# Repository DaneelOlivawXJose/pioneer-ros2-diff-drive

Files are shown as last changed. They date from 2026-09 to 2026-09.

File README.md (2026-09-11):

<div align="center">

# 🤖 Pioneer-X | Autonomous Differential Drive Robot

### A full-stack robotics project — from Electronics to real-time control dashboards

**Mechanical design · Electronics · Embedded firmware · ROS 2 · Control Algorithms · Custom SCADA (React)**







<!-- 🖼️ PLACEHOLDER: Add more badges if relevant — e.g. Docker, KiCad, Fusion360, micro-ROS, Node version -->

</div>

---

## 📌 About this project

This is a **fully built, working, from-scratch differential-drive mobile robot**, inspired by the classic Pioneer research platforms — but extended into a complete robotics stack that could be upgraded any time.

This repository is **not a tutorial**. It is a **portfolio**: the complete set of design files, source code, firmware, and control software behind a robot that physically exists, drives, localizes itself, and can be commanded and monitored in real time through a custom web-based SCADA I built in React.

> ⚠️ *This is proof-of-work documentation. Build instructions, BOM sourcing tips, and step-by-step guides are intentionally out of scope — the goal is to showcase the integrated system as it currently stands.*

### 🚧 Status: Active Development

This project is **not a closed, finished product** — it's designed and built as an **open testbed platform**. The mechanical structure, electronics, firmware, and ROS 2 architecture were all built with extensibility as a first-class goal:

- 🧩 **New control/path-tracking algorithms** can be dropped in as independent ROS 2 nodes and selected live from the SCADA, without touching the rest of the stack.
- 🔌 **New hardware accessories** (sensors, actuators, additional boards) can be integrated thanks to the modular electronics layout and the firmware/ROS 2 separation of concerns.
- 🧪 The whole point of the SCADA is to make this platform easy to **test, compare, and iterate on** — swap an algorithm, watch the telemetry, tune it, repeat.

In short: this repo is a living platform for experimenting with mobile robot control and hardware, not a one-off build. Expect ongoing commits, new algorithms, and new accessories over time — see the [Roadmap](#-roadmap).

<!-- ✍️ DEVELOP MORE: 1-2 paragraphs here about WHY you built this — personal motivation, what gap you wanted to fill, what you wanted to learn/prove (control theory? full-stack robotics? SCADA/HMI design? building an extensible research platform?). This is the part recruiters/visitors read first. -->

---

## 🎥 Demonstrations

<!-- 🖼️ PLACEHOLDER: This section sells the project. Embed real GIFs/videos. GitHub renders GIFs inline; for longer videos, link to YouTube with a thumbnail. -->

| Autonomous navigation | Real-time SCADA monitoring | Manual teleoperation |
|---|---|---|
| nav | scada | teleop |

<!-- ✍️ DEVELOP MORE: Add a "Full demo video" section here with a YouTube/Drive link, ideally 2-4 minutes showing: boot-up, teleop, autonomous path-following with each algorithm, and the SCADA reacting live. -->

---

## 🧭 Table of Contents

- [System Overview](#-system-overview)
- [Hardware](#-hardware)
- [Electronics & Wiring](#-electronics--wiring)
- [Firmware (ESP32)](#-firmware-esp32)
- [ROS 2 Software Stack](#-ros-2-software-stack)
- [Control & Path-Tracking Algorithms](#-control--path-tracking-algorithms)
- [SCADA / Web HMI (React)](#-scada--web-hmi-react)
- [Localization](#-localization)
- [Repository Structure](#-repository-structure)
- [Tech Stack Summary](#-tech-stack-summary)
- [Results & Performance](#-results--performance)
- [Roadmap](#-roadmap)
- [License](#-license)
- [Author](#-author)

---

## 🏗️ System Overview

<!-- 🖼️ PLACEHOLDER: High-level architecture diagram — boxes for ESP32 <-> micro-ROS/serial <-> ROS2 (Nav stack, controllers, EKF) <-> rosbridge/WebSocket <-> React SCADA. Draw it in draw.io/excalidraw and export as PNG/SVG into docs/media/ -->

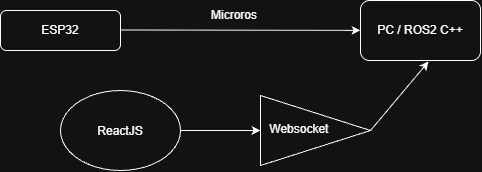
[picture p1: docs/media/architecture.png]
Architecture Diagram


The robot is organized into three integrated layers:

| Layer | Responsibility | Tech |
|---|---|---|
| **Low-level control** | Motor driving, encoder reading, PID velocity loops, sensor interfacing | ESP32 (C/C++) |
| **High-level autonomy** | Localization, path planning, trajectory tracking, control algorithms | ROS 2 |
| **Supervision (SCADA)** | Real-time visualization, teleoperation, algorithm selection, telemetry | React + WebSocket/rosbridge |

<!-- ✍️ DEVELOP MORE: Describe the communication pipeline in detail — e.g. "ESP32 publishes wheel odometry over serial/micro-ROS at X Hz, ROS2 fuses it with IMU via robot_localization EKF, Nav2/custom controller node computes cmd_vel, rosbridge_server exposes topics over WebSocket, React subscribes via roslibjs." -->

---

## ⚙️ Hardware

<!-- 🖼️ PLACEHOLDER: CAD renders — exploded view, chassis, wheel assembly, top view with dimensions -->

<p align="center">
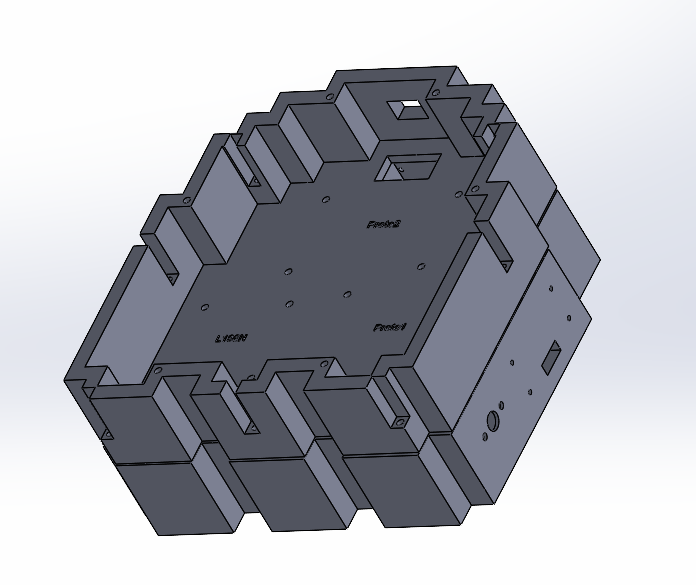
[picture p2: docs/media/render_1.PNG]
  
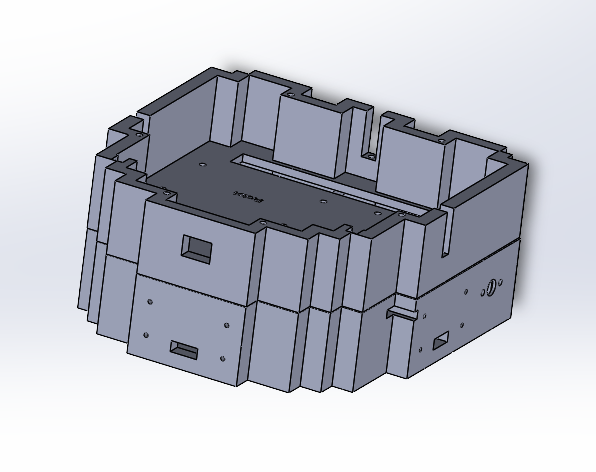
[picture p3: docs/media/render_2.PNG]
  
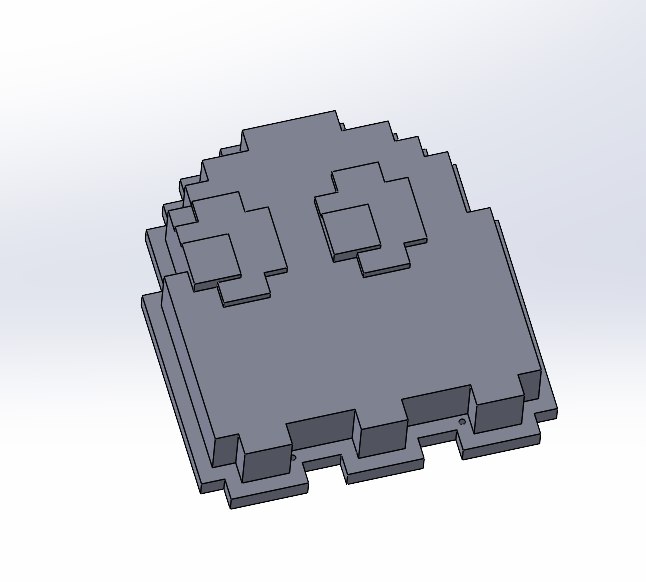
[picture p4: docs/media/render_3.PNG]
  
</p>

- **Chassis:** custom-designed, differential drive, [material/manufacturing — 3D printed]
- **Drive:** 2x DC gear motors + encoders, L298 Driver.
- **CAD files:** provided in [`/hardware/cad`](./hardware/cad) (STEP, native format, and STL for printing)

📄 **Full Bill of Materials:** [`/hardware/BOM.xlsx`](./hardware/BOM.xlsx)

<!-- ✍️ DEVELOP MORE: Table with key specs — dimensions, weight, wheel diameter, wheelbase, max speed, battery/autonomy, payload, sensor list (LiDAR? camera? IMU? ultrasonic?). This is important for anyone evaluating the robot's real capabilities. -->

| Spec | Value |
|---|---|
| Dimensions (L×W×H) | 500x450x100 mm |
| Weight | 600g |
| Max linear speed | 4.0 m/s |
| Battery / autonomy | 3h |

---

## 🔌 Electronics & Wiring

- Pin mapping source of truth: [`/firmware/esp32_code/esp32_code.ino`](./firmware/esp32_code/esp32_code.ino) — every pin below is taken directly from the running firmware, not from a separate (and easily outdated) diagram.
### Core components
 
| Component | Qty | Role | Notes |
|---|---|---|---|
| **ESP32 Dev Board** | 1 | Main controller — runs micro-ROS, PID loops, sensor filtering | Communicates with the ROS 2 side over WiFi via micro-ROS (`set_microros_wifi_transports`) |
| **L298N Dual H-Bridge** | 1 | Drives both DC motors | Controlled via 2 PWM-capable pins per motor (no separate ENA/ENB — direction and speed are combined through both inputs, see table below) |
| **DC Gearmotor + Encoder** | 2 | Traction (differential drive) | Quadrature encoders, read via hardware interrupts on both channels for direction-aware counting |
| **US-016 Analog Ultrasonic Sensor** | 3 | Front obstacle detection | Each sensor has its own dedicated **2nd-order Butterworth low-pass filtering circuit** on the analog output before reaching the ESP32 ADC |
| **18650 Li-ion cells** | 2 | Main power source for motors/logic rail | Feed the charger/boost module below |
| **Type-C Li-ion Charger + DC-DC Boost Module (15 W, 3 A, 9 V out, UPS-style)** | 1 | Battery management + step-up to 9 V | Charges the 2×18650 pack via USB-C while also acting as a boost converter, delivering a stable 9 V rail to the L298N — UPS-style topology means the robot can charge and stay powered at the same time |
| **Phone power bank** | 1 | Dedicated 5 V supply for the ESP32 | Electrically decoupled from the motor power rail — keeps motor-driver switching noise away from the microcontroller's logic supply. Prevents shutting down due to current |
 
<!-- ✍️ DEVELOP MORE: link your exact ESP32 board model, L298N vendor, DC motor/encoder specs (gearbox ratio, encoder PPR), and add real purchase/datasheet links where you have them. -->
 
### Power architecture
 
The robot deliberately runs **two independent power domains**:
 
1. **Motor / actuation rail (9 V):** 2×18650 cells → Type-C charger/boost module → 9 V → L298N → motors. The boost module's UPS behavior allows charging without powering the robot down.
2. **Logic rail (5 V):** a standalone phone power bank feeds the ESP32 directly over USB.
This separation avoids voltage sag and PWM switching noise from the motors affecting the ESP32's ADC readings — which matters here, since the ultrasonic sensors are read as raw analog voltages and are sensitive to supply noise.
Also sometimes when starting the motors, the current was so high that restarted all the system, this power bank prevents this issue.
 
### Motor driver (L298N) pin mapping
 
| Signal | ESP32 Pin | Notes |
|---|---|---|
| Left motor – IN1 | `GPIO 32` | PWM output (`ledcAttach`, 25 kHz, 10-bit) |
| Left motor – IN2 | `GPIO 33` | PWM output |
| Right motor – IN1 | `GPIO 27` | PWM output |
| Right motor – IN2 | `GPIO 14` | PWM output |
 
Each motor is driven by **two PWM channels instead of a PWM+direction pair**: forward/reverse and speed are both encoded by driving one of the two `INx` pins with a PWM duty cycle while the other stays at 0 (see `setMotorL` / `setMotorR` in the firmware). This removes the need for separate `ENA`/`ENB` enable lines.
 
### Encoders (quadrature, interrupt-driven)
 
| Signal | ESP32 Pin | Notes |
|---|---|---|
| Left encoder – Channel A | `GPIO 25` | `INPUT_PULLUP`, `CHANGE` interrupt |
| Left encoder – Channel B | `GPIO 26` | `INPUT_PULLUP`, `CHANGE` interrupt |
| Right encoder – Channel A | `GPIO 12` | `INPUT_PULLUP`, `CHANGE` interrupt |
| Right encoder – Channel B | `GPIO 13` | `INPUT_PULLUP`, `CHANGE` interrupt |
 
Both channels of each encoder trigger their own ISR, comparing A/B state to determine direction — giving full quadrature resolution (4x counting) rather than relying on a single edge.
 
### Ultrasonic sensors (US-016, analog)
 
| Signal | ESP32 Pin | ADC | Notes |
|---|---|---|---|
| Sensor 1 (analog out) | `GPIO 36` | ADC1_CH0 | Voltage divider + 2nd-order Butterworth filter upstream |
| Sensor 2 (analog out) | `GPIO 39` | ADC1_CH3 | Voltage divider + 2nd-order Butterworth filter upstream |
| Sensor 3 (analog out) | `GPIO 34` | ADC1_CH6 | 2nd-order Butterworth filter upstream (read directly in mV, no divider) |
 
All three run on ADC1 (safe to use alongside WiFi, unlike ADC2). Each sensor's raw output passes through a dedicated **2nd-order Butterworth low-pass filter** before reaching the ESP32, reducing high-frequency noise at the hardware level; the firmware then applies a further **median filter (7 samples) + exponential smoothing (α = 0.3)** in software, read continuously from a dedicated FreeRTOS task (`tareaLecturaUS016`) so sensor sampling never blocks the ROS 2 executor or the PID control loop.
 
### Status LED
 
| Signal | ESP32 Pin | Notes |
|---|---|---|
| Onboard status LED | `GPIO 2` | Blinks/toggles on obstacle detection and on odometry reset, doubles as a fatal-error indicator (`error_loop`) |
 
<!-- 🖼️ PLACEHOLDER: A labeled photo of the real wiring inside the chassis, matching the tables above, is worth more here than any diagram. -->

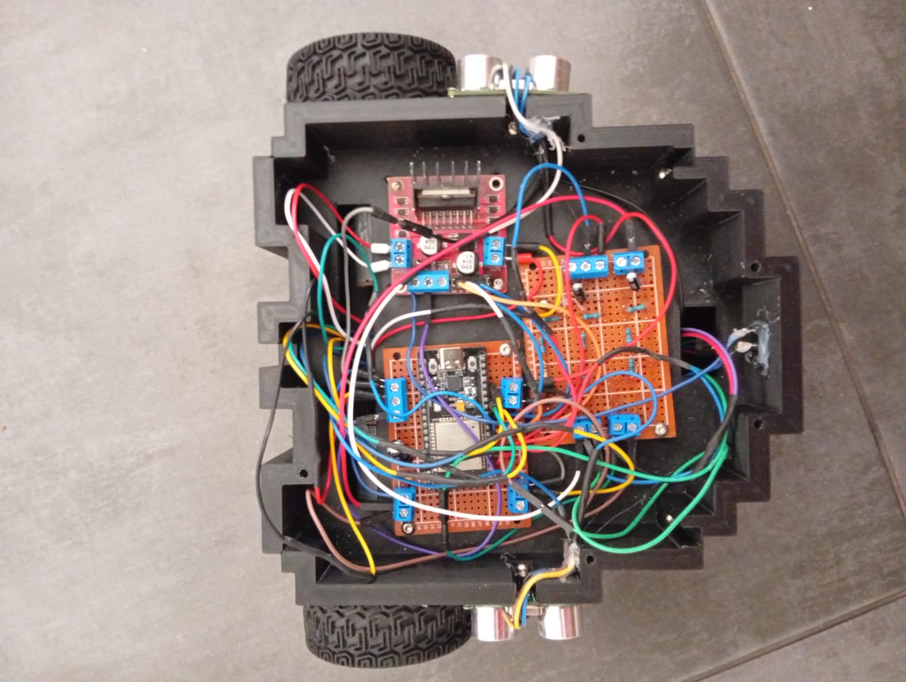
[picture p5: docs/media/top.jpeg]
Top-down view

 
---

## 🐢 ROS 2 Software Stack

Location: [`/ros2_ws/src`](./ros2_ws/src)

<!-- 🖼️ PLACEHOLDER: rqt_graph screenshot showing your actual node/topic graph -->

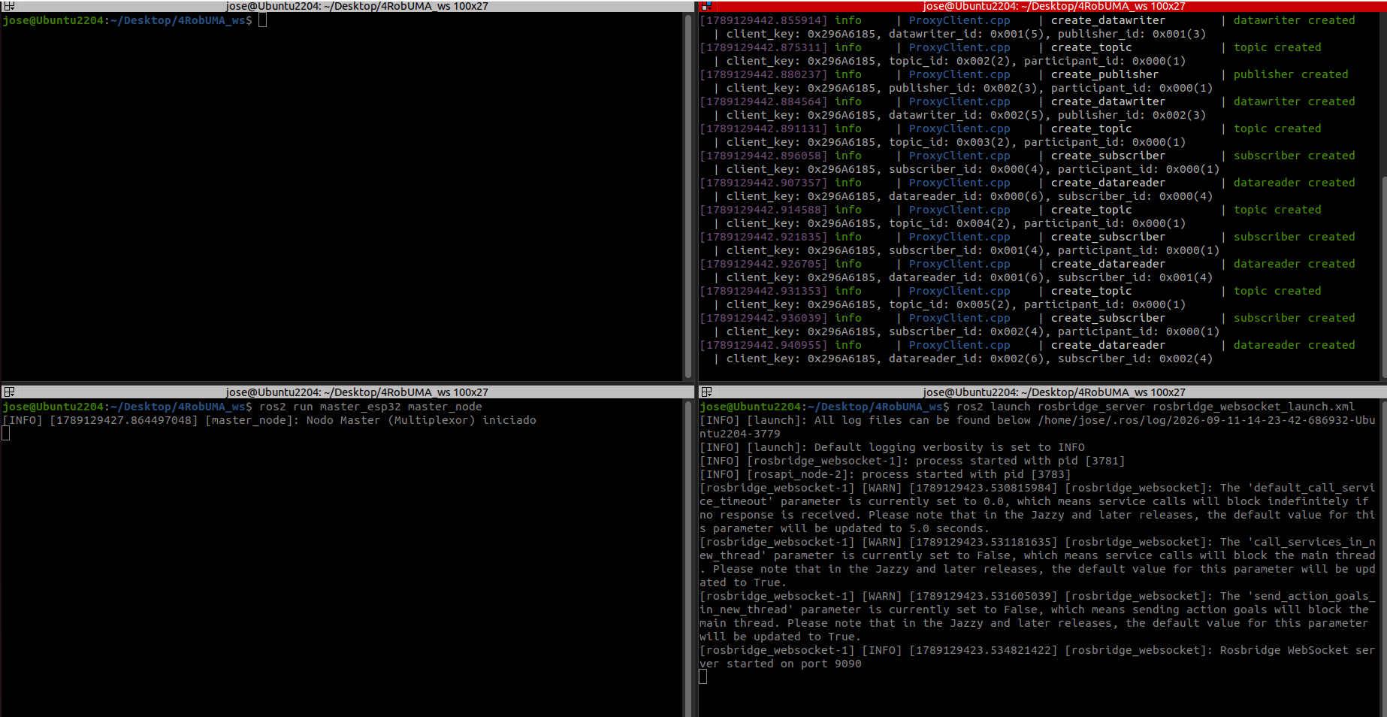
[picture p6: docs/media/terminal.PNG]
Ubuntu Terminal


Custom ROS 2 packages built for this robot. The architecture keeps control algorithms and hardware interfaces decoupled into their own packages/nodes, so new ones can be added without modifying the core stack.

### 🧠 Master / Orchestrator architecture
 
Rather than launching every control node at once and switching behavior through internal flags, this stack uses a **master (orchestrator) node** that supervises which algorithm is actually running:
 
1. The **master node** stays up permanently, subscribed to a command topic (e.g. `/control/select_algorithm`).
2. When a command arrives on that topic — coming from the SCADA, a CLI call, or any other client — the master **launches the corresponding control node as its own process** (e.g. `ros2 run pioneer_control mpc_node`), rather than that node being active from boot.
3. The incoming message is **forwarded to the newly launched node** (as a parameter, an initial topic message, or a service call, depending on the node), so it starts already configured with the requested behavior.
4. If a different algorithm is requested while one is already running, the master **stops/kills the current control node's process first**, then spawns the new one — guaranteeing only one control node is ever commanding the robot at a time.
This keeps every control algorithm fully decoupled: each one lives in its own node/process, with no shared state, and the master is the single source of truth for *which* algorithm currently owns `cmd_vel`. Adding a new algorithm means writing a new node and registering it with the master — no changes to the rest of the stack.
 
### ▶️ How to Run
 
Typical startup sequence, in order:
 
1. **Start the micro-ROS agent** (bridges the ESP32's WiFi micro-ROS client to the ROS 2 graph):
```bash
   ros2 run micro_ros_agent micro_ros_agent udp4 --port 8888
```
 
2. **Power on the robot / reset the ESP32** so it connects to the agent above (watch the serial monitor or the agent log for a successful handshake).
3. **Launch the rosbridge server**
```bash
   ros2 launch rosbridge_server rosbridge_websocket_launch.xml
```
 
4. **Launch the master/orchestrator node**, which will stay running and wait for algorithm-selection commands:
```bash
   ros2 run master_esp32 master_node
```
 
5. **Start the SCADA dashboard**:
```bash
   npm run dev
```

## 🎯 Control & Path-Tracking Algorithms

One of the standout features of this project: the robot supports **multiple, hot-swappable trajectory-tracking algorithms**, selectable live from the SCADA.

| Algorithm | Description | Status |
|---|---|---|
| **Proportional** | Classic proportional controller | ✅ Implemented |
| **Follow the Carrot** | Classic pursuit of a moving lookahead point on the path | ✅ Implemented |
| **MPC (Model Predictive Control)** | Optimization-based control over a prediction horizon | ✅ Implemented |
| **Implicit Path Following** | Based on references like 1 wall / 2 wall / Moving objective | ✅ Implemented |

<!-- ✍️ DEVELOP MORE: This is your strongest technical differentiator — expand heavily here.
For EACH algorithm, add:
- Short explanation of the math/approach used
- Key tunable parameters (lookahead distance, horizon length, weights, constraints)
- A GIF/plot comparing behavior (e.g. tracking error over time) between algorithms on the same path
- Why you chose to implement each one / what you learned
Consider linking to a `/docs/control_theory.md` or similar for the deep technical writeup, and keeping this section as a summary. -->
Every algorithm is tunnable from scada:
| Pure Pursuit | MPC |
|---|---|
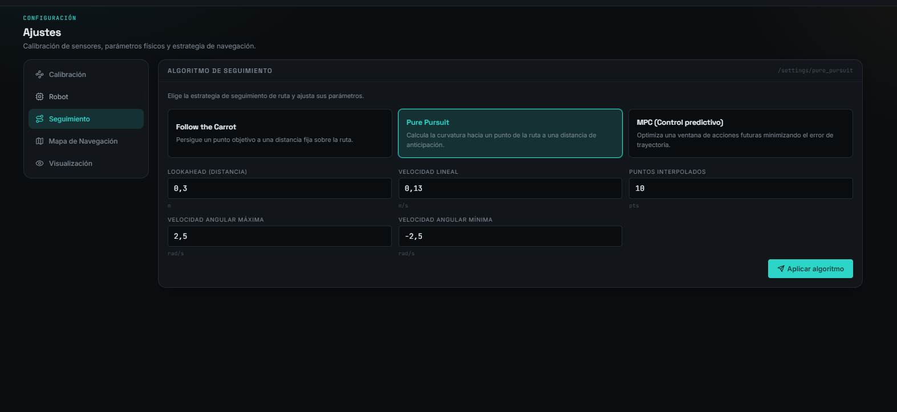
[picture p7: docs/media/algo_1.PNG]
Pure Pursuit
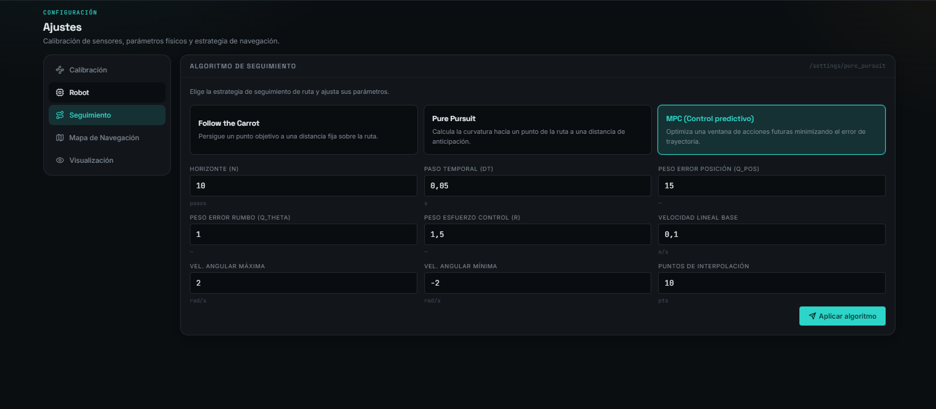
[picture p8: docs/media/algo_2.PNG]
MPC
|  |  |

---

## 🖥️ SCADA / Web HMI (React)

Location: [`/scada`](./scada)

<!-- 🖼️ PLACEHOLDER: Screenshot or GIF of the dashboard — ideally a few, showing: live map/localization, telemetry panel, algorithm selector, manual command panel -->

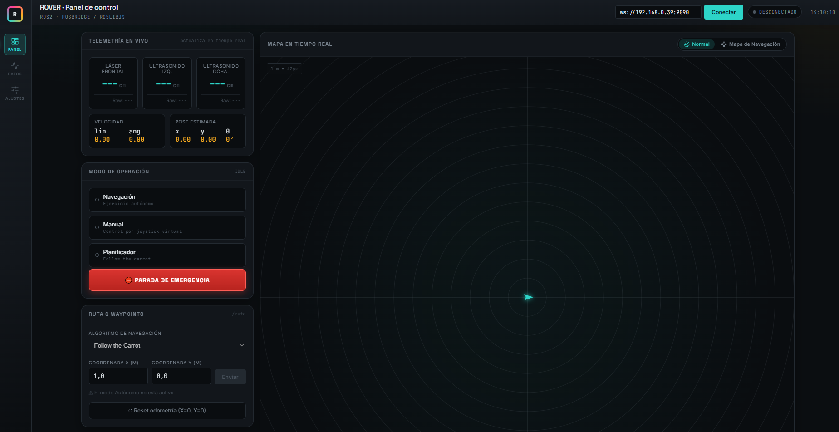
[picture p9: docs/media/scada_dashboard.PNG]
SCADA Dashboard


A custom-built, real-time supervisory dashboard, developed entirely in React, that connects directly to the ROS 2 stack:

- 📍 **Real-time localization view** — live robot pose over the map/path
- 🎮 **Manual command interface** — teleoperation, direct velocity commands
- 🤖 **Robot parameters tunner** — width, wheel radius, ...
- 🔀 **Algorithm selector** — switch between MPC / Follow the Carrot / others on the fly
- 📊 **Live telemetry** — velocities, battery, control errors, system status
- 📡 **Sensor Calibration** — lineal, cuadratic, least square adjustment
- 🛑 **Safety controls** — *(e-stop, connection status, etc)*

**Stack:** React, [state management — Redux/Zustand/Context], [charting — Recharts/D3/Plotly], [ROS bridge — roslibjs + rosbridge_suite / custom WebSocket server]

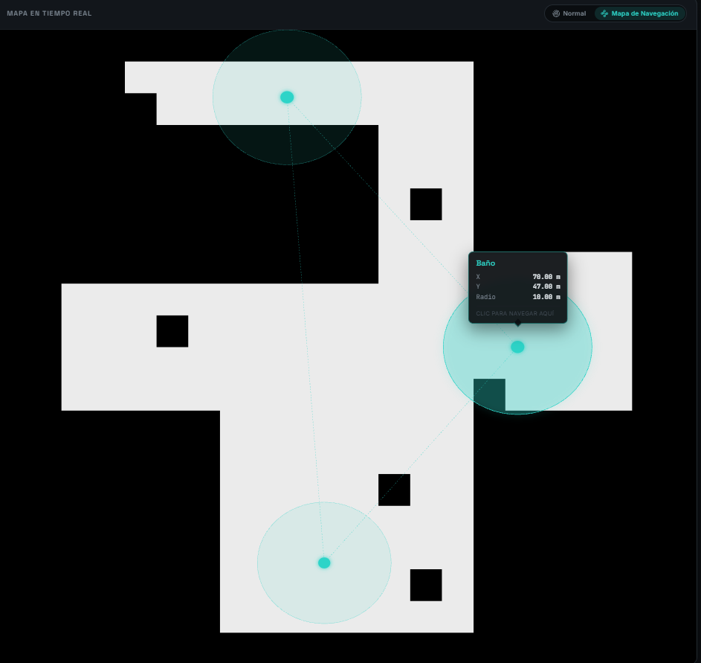
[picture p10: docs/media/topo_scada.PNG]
SCADA Topologic Planning


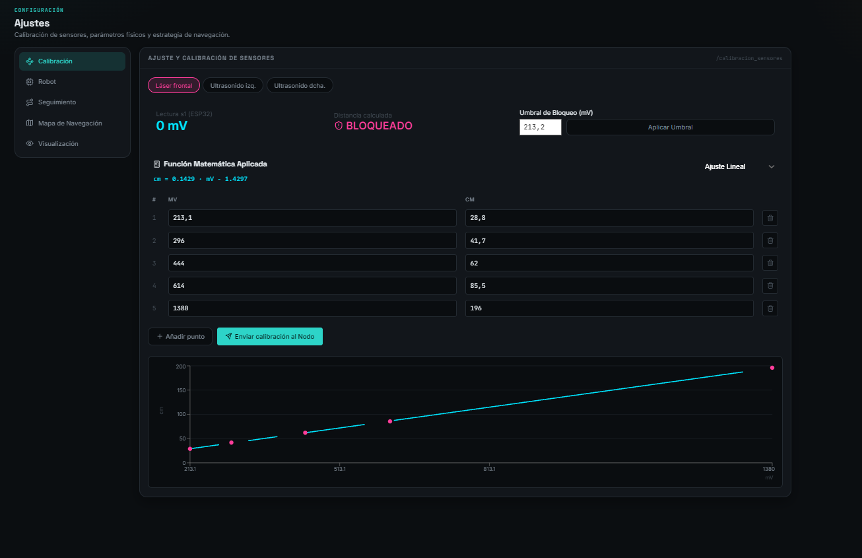
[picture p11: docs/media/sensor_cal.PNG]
SCADA Sensor Calibration


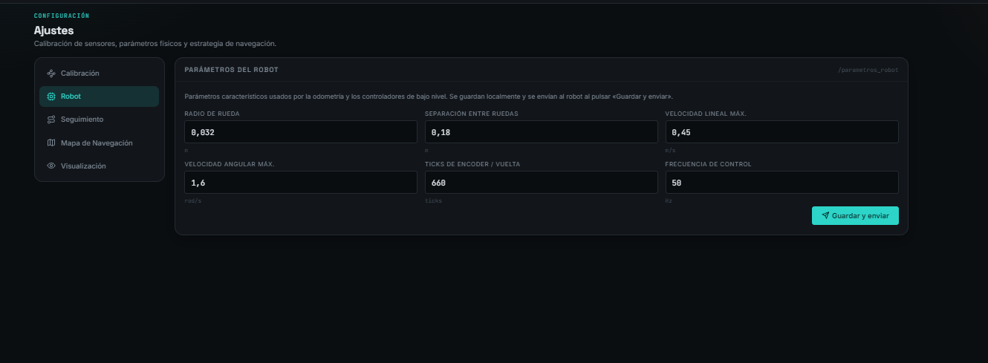
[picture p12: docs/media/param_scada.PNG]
SCADA Robot Parameters


## 🧰 Tech Stack Summary

<div align="center">








</div>

---

## 🗺️ Roadmap

<!-- ✍️ DEVELOP MORE: List what's next — shows the project is alive and you have vision beyond "finished." e.g.: -->

- [ ] SLAM-based mapping support
- [ ] Multi-robot fleet view in SCADA
- [ ] Obstacle avoidance layer
- [ ] Dockerized ROS 2 + SCADA deployment
- [ ] Simulation environment (Gazebo/Ignition digital twin)

---

## 📄 License

This project is licensed under the [MIT License](./LICENSE) — feel free to reference or learn from it; attribution appreciated.

<!-- ✍️ Confirm this matches your actual chosen license (MIT / Apache-2.0 / GPL, etc.) and add the LICENSE file to the repo root. -->

---

## 👤 Author

**Jose Segura Montes**
Robotics / Mechatronics engineer

<!-- ✍️ DEVELOP MORE: Add links — LinkedIn, personal site, email, other projects -->




<div align="center">

*4 8 15 16 23 42*

</div>

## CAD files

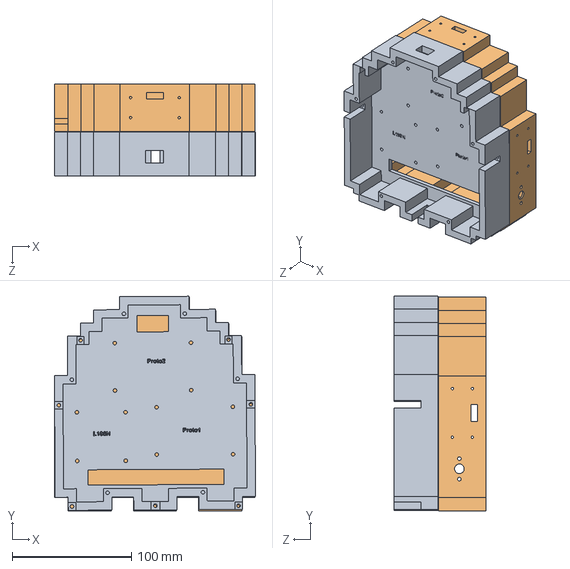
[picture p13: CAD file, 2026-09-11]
hardware/cad/EnsamblajeRobot.SLDASM
168.7 x 180.0 x 77.6 mm
MainBase
ParteElectronica

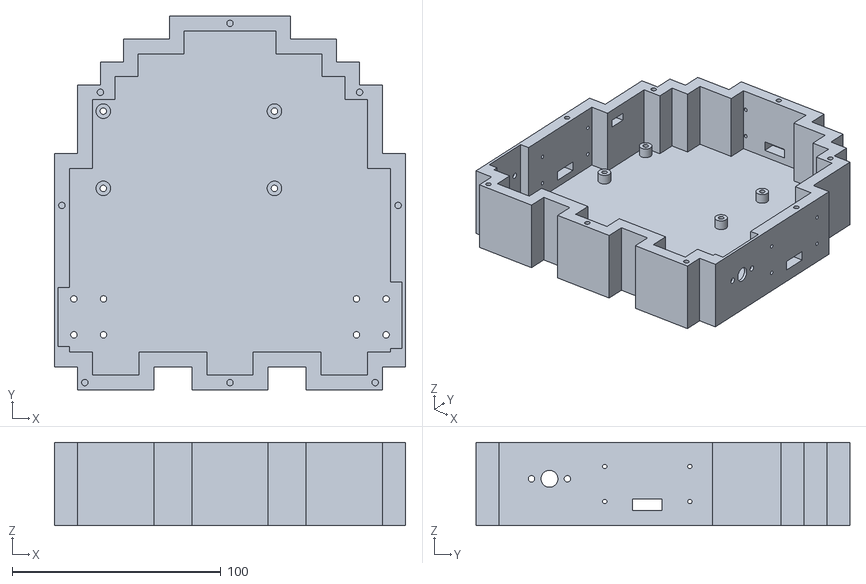
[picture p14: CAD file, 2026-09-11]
hardware/cad/Imprimir/MainBase.STL
168.2 x 179.2 x 40.0

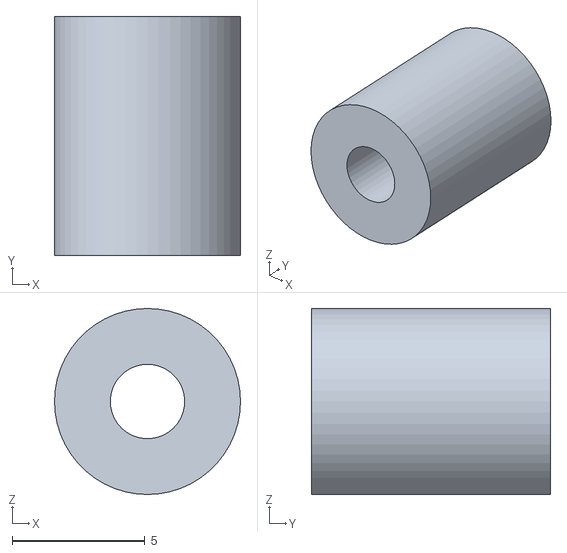
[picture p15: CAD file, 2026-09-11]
hardware/cad/Imprimir/SoportesAtornillas.STL
7.00 x 9.00 x 7.00

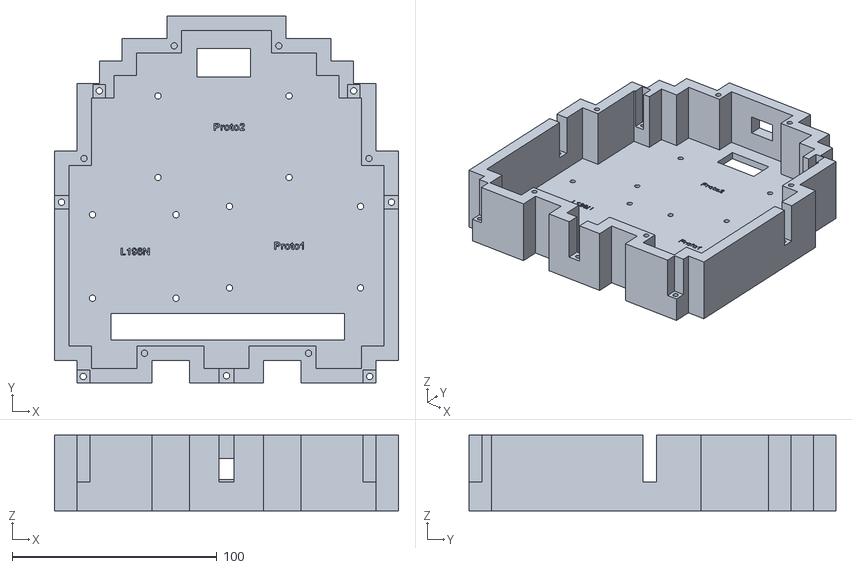
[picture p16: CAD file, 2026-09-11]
hardware/cad/Imprimir/ParteElectronica.STL
168.2 x 179.2 x 37.0

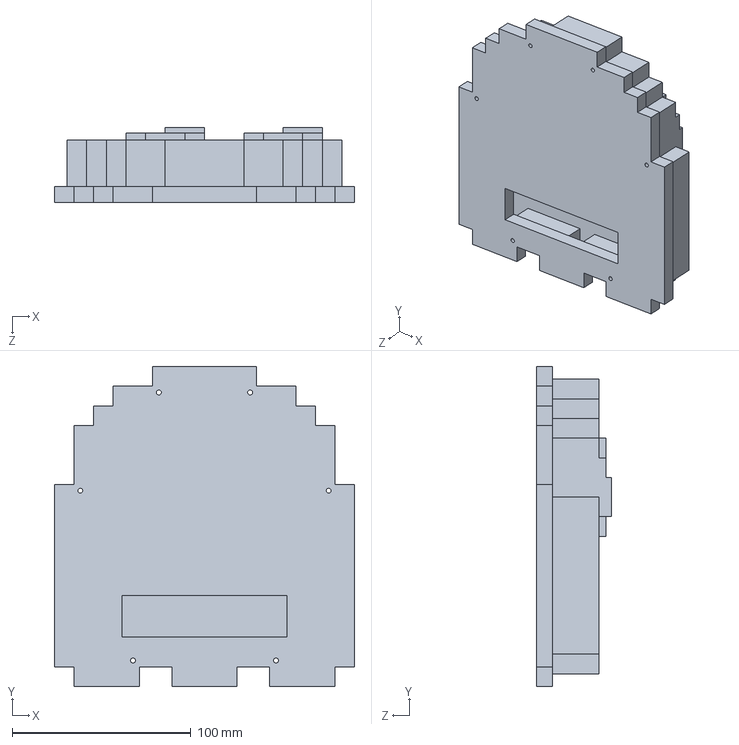
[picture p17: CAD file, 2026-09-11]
hardware/cad/Tapa.SLDPRT
168.2 x 179.2 x 42.0 mm

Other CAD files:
hardware/cad/MainBase.SLDPRT
hardware/cad/SoportesAtornillas.SLDPRT
hardware/cad/Imprimir/Tapa.STL
hardware/cad/ParteElectronica.SLDPRT

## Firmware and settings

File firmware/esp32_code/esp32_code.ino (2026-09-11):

#include <Arduino.h>
#include <micro_ros_arduino.h>
#include <stdio.h>
#include <rcl/rcl.h>
#include <rcl/error_handling.h>
#include <rclc/rclc.h>
#include <rclc/executor.h>
#include <std_msgs/msg/string.h>
#include <geometry_msgs/msg/twist.h>
#include <geometry_msgs/msg/point.h>
#include <std_msgs/msg/int32_multi_array.h>
#include <std_msgs/msg/int32.h>
#include <std_msgs/msg/float32_multi_array.h>
#include <WiFi.h>

#if !defined(ESP32)
#error This example is only available for ESP32
#endif

// ==========================================
//   CONFIGURACIÓN
// ==========================================

rcl_node_t node;
rclc_support_t support;
rcl_allocator_t allocator;
rclc_executor_t executor;

// Publicadores
rcl_publisher_t publisher; // Odometría (ticks)
rcl_publisher_t publisher_laser; // Sensor Distancia (MultiArray)
rcl_publisher_t pub_pos_estimada;
std_msgs__msg__Int32MultiArray encoder_msg;
std_msgs__msg__Float32MultiArray laser_msg; // Mensaje de 3 posiciones
geometry_msgs__msg__Point pos_msg;

// Suscriptor
rcl_subscription_t subscriber;
geometry_msgs__msg__Twist msg_sub;

rcl_subscription_t subscriber_settings;
std_msgs__msg__Float32MultiArray msg_sub_settings;

rcl_subscription_t subscriber_reset;
std_msgs__msg__Int32 msg_reset;

// PINES
#define LED_PIN 2

// --- VARIABLES DE ESTADO ---
volatile bool sistema_seguro = false;
volatile bool obstaculo_delante = false;

const int frecuencia = 25000;

// --- MOTORES ---
const int IN1_L = 32; const int IN2_L = 33;
const int PIN_A_L = 25; const int PIN_B_L = 26; 
const int IN1_R = 27; const int IN2_R = 14;
const int PIN_A_R = 12; const int PIN_B_R = 13; 

// --- CINEMÁTICA Y PID ---
const double RADIO_RUEDA = 0.0347;
const double ANCHO_ROBOT = 0.1941;
const float DELTA_T_S = 0.01; // 10ms
const float CUENTAS_POR_REV_TOTAL = 1564.65;
const float FACTOR_CUENTAS_A_RADS = (2.0 * 3.14159265) / CUENTAS_POR_REV_TOTAL;

double pos_x_global = 0.0;
double pos_y_global = 0.0;
double theta_actual = 0.0;
long sl_prev = 0;
long sr_prev = 0;

// PID CONSTANTES
const double Kp_L = 40.289; const double Ki_L = 1120.3135; const double Kd_L = 0.0;
const double Kp_R = 19.6078; const double Ki_R = 586.746; const double Kd_R = 0.0;

// Variables PID
volatile double target_L = 0.0;
volatile double target_R = 0.0;

volatile long contador_L = 0;
long contador_L_ant = 0;
double error_acumulado_L = 0.0;
double error_anterior_L = 0.0;

volatile long contador_R = 0;
long contador_R_ant = 0;
double error_acumulado_R = 0.0;
double error_anterior_R = 0.0;

// Hardware Timers y Mux
hw_timer_t *timer = NULL;
portMUX_TYPE timerMux = portMUX_INITIALIZER_UNLOCKED;
portMUX_TYPE paramMux = portMUX_INITIALIZER_UNLOCKED;

#define RCCHECK(fn) { \
  rcl_ret_t temp_rc = fn; \
  if ((temp_rc != RCL_RET_OK)) { \
    Serial.print("Fallo en inicialización de ROS. Código de error: "); \
    Serial.println((int)temp_rc); \
    Serial.println("Reiniciando ESP32 en 3 segundos..."); \
    delay(3000); \
    ESP.restart(); \
  } \
}
#define RCSOFTCHECK(fn) { rcl_ret_t temp_rc = fn; if((temp_rc != RCL_RET_OK)){ Serial.print("MicroROS Error Code: "); Serial.println((int)temp_rc); }}

// ==========================================
//   CONFIGURACIÓN DE SENSORES US-016
// ==========================================
const int NUM_MUESTRAS = 7;
const float MULTIPLICADOR_RC = 1.5; // Divisor de tensión (3/2)
const float alfa = 0.3;

struct US016Sensor {
  uint8_t pin;
  float lecturas[NUM_MUESTRAS];
  float voltaje_mV;
  float voltaje_mV_anterior_suavizado;
  float voltaje_mV_minimo;
};

// Instanciamos los 3 sensores
US016Sensor sensores[3] = {
  {36, {0}, 0.0, 0.0, 100.0},
  {39, {0}, 0.0, 0.0, 100.0},
  {34, {0}, 0.0, 0.0, 100.0}
};

float obtenerMediana(float array[], int size)
{
  float tempArray[size];
  memcpy(tempArray, array, size * sizeof(float));
  
  for(int i = 0; i < (size - 1); i++) {
    for(int j = 0; j < (size - (i + 1)); j++) {
      if(tempArray[j] > tempArray[j+1]) {
        float t = tempArray[j];
        tempArray[j] = tempArray[j+1];
        tempArray[j+1] = t;
      }
    }
  }
  return tempArray[size / 2];
}

void inicializarSensor(US016Sensor &sensor)
{
  for (int i = 0; i < NUM_MUESTRAS; i++) {
    sensor.lecturas[i] = analogReadMilliVolts(sensor.pin) * MULTIPLICADOR_RC;
    delay(20);
  }
  float medianaInicial = obtenerMediana(sensor.lecturas, NUM_MUESTRAS);
  sensor.voltaje_mV = medianaInicial;
  sensor.voltaje_mV_anterior_suavizado = medianaInicial;
}



// Tarea en segundo plano para leer y filtrar
void tareaLecturaUS016(void *pvParameters)
{
  for(;;)
  {
    for (int s = 0; s < 3; s++)
    {
      for (int i = 0; i < NUM_MUESTRAS - 1; i++)
      {
        sensores[s].lecturas[i] = sensores[s].lecturas[i + 1];
      }

      float nuevaLectura_mV = 0.0;
      if (sensores[s].pin != 34)
      {
        nuevaLectura_mV = analogReadMilliVolts(sensores[s].pin) * MULTIPLICADOR_RC;
      } else {
        nuevaLectura_mV = analogReadMilliVolts(sensores[s].pin);
      }
      
      sensores[s].lecturas[NUM_MUESTRAS - 1] = nuevaLectura_mV;

      float mediana = obtenerMediana(sensores[s].lecturas, NUM_MUESTRAS);

      sensores[s].voltaje_mV = alfa * mediana + (1 - alfa) * sensores[s].voltaje_mV_anterior_suavizado;
      sensores[s].voltaje_mV_anterior_suavizado = sensores[s].voltaje_mV;
    }
    vTaskDelay(pdMS_TO_TICKS(50));
  }
}

// ==========================================
//   FUNCIONES BÁSICAS Y RUTINAS
// ==========================================
void pararMotores()
{
  ledcWrite(IN1_L, 0); ledcWrite(IN2_L, 0);
  ledcWrite(IN1_R, 0); ledcWrite(IN2_R, 0);
}

void error_loop() {
  Serial.println("!!! ERROR FATAL !!!");
  pararMotores();
  while (1) {
    digitalWrite(LED_PIN, !digitalRead(LED_PIN)); delay(200);
  }
}

void IRAM_ATTR isr_L_A() { if(digitalRead(PIN_A_L)==digitalRead(PIN_B_L)) contador_L--; else contador_L++; }
void IRAM_ATTR isr_L_B() { if(digitalRead(PIN_A_L)!=digitalRead(PIN_B_L)) contador_L--; else contador_L++; }
void IRAM_ATTR isr_R_A() { if(digitalRead(PIN_A_R)==digitalRead(PIN_B_R)) contador_R++; else contador_R--; } 
void IRAM_ATTR isr_R_B() { if(digitalRead(PIN_A_R)!=digitalRead(PIN_B_R)) contador_R++; else contador_R--; }

void setMotorL(int pwm) {
  if (pwm > 1023) pwm = 1023; if (pwm < -1023) pwm = -1023;
  if (pwm >= 0) { ledcWrite(IN1_L, pwm); ledcWrite(IN2_L, 0); }
  else { ledcWrite(IN1_L, 0); ledcWrite(IN2_L, -pwm); }
}

void setMotorR(int pwm) {
  if (pwm > 1023) pwm = 1023; if (pwm < -1023) pwm = -1023;
  if (pwm >= 0) { ledcWrite(IN1_R, pwm); ledcWrite(IN2_R, 0); }
  else { ledcWrite(IN1_R, 0); ledcWrite(IN2_R, -pwm); }
}

double calcularPID(double ref, double medicion, double &err_acum, double &err_prev, double Kp, double Ki, double Kd) {
  double error = ref - medicion;
  err_acum += error * DELTA_T_S;
  
  double max_I = 1023.0; 
  if (Ki > 0) max_I = 1023.0 / Ki;
  if (err_acum > max_I) err_acum = max_I;
  if (err_acum < -max_I) err_acum = -max_I;

  err_prev = error;
  return (Kp * error) + (Ki * err_acum);
}

void IRAM_ATTR onTimerPID() {
  bool intentando_avanzar = (target_L > 0 && target_R > 0);

  if (!sistema_seguro || (obstaculo_delante && intentando_avanzar)) {
    pararMotores();
    error_acumulado_L=0; error_anterior_L=0;
    error_acumulado_R=0; error_anterior_R=0;
    return;
  }

  double ref_L, ref_R;
  portENTER_CRITICAL_ISR(&paramMux);
  ref_L = target_L; ref_R = target_R;
  portEXIT_CRITICAL_ISR(&paramMux);

  long pos_L, pos_R;
  portENTER_CRITICAL_ISR(&timerMux);
  pos_L = contador_L; pos_R = contador_R;
  portEXIT_CRITICAL_ISR(&timerMux);

  double vel_L = ((double)(pos_L - contador_L_ant) / DELTA_T_S) * FACTOR_CUENTAS_A_RADS;
  double vel_R = ((double)(pos_R - contador_R_ant) / DELTA_T_S) * FACTOR_CUENTAS_A_RADS;
  
  contador_L_ant = pos_L; contador_R_ant = pos_R;

  double out_L = calcularPID(ref_L, vel_L, error_acumulado_L, error_anterior_L, Kp_L, Ki_L, Kd_L);
  double out_R = calcularPID(ref_R, vel_R, error_acumulado_R, error_anterior_R, Kp_R, Ki_R, Kd_R);

  setMotorL((int)out_L); setMotorR((int)out_R);
}

void calcular_posicion() {
  long sl_curr = contador_L;
  long sr_curr = contador_R;

  long delta_l_ticks = sl_curr - sl_prev;
  long delta_r_ticks = sr_curr - sr_prev;
  sl_prev = sl_curr;
  sr_prev = sr_curr;

  double sl = 2.0 * PI * RADIO_RUEDA * ((double)delta_l_ticks / CUENTAS_POR_REV_TOTAL);
  double sr = 2.0 * PI * RADIO_RUEDA * ((double)delta_r_ticks / CUENTAS_POR_REV_TOTAL);

  double dx_l = 0, dy_l = 0, dt = 0;

  if (abs(sr - sl) < 1e-6) {
    dx_l = (sr + sl) / 2.0;
  } else {
    double l = ANCHO_ROBOT;
    double common = ((sr + sl) / (sr - sl)) * (l / 2.0);
    double arg = (sr - sl) / l;
    dx_l = common * sin(arg);
    dy_l = common * (1.0 - cos(arg));
    dt = arg;
  }

  double dx_g = dx_l * cos(theta_actual) - dy_l * sin(theta_actual);
  double dy_g = dx_l * sin(theta_actual) + dy_l * cos(theta_actual);

  pos_x_global += dx_g;
  pos_y_global += dy_g;
  theta_actual += dt;

  while(theta_actual > PI) theta_actual -= 2*PI;
  while(theta_actual < -PI) theta_actual += 2*PI;
}

void reset_callback(const void * msgin) {
  const std_msgs__msg__Int32 * msg = (const std_msgs__msg__Int32 *)msgin;
  if (msg->data == 1) {
    portENTER_CRITICAL(&paramMux);
    pos_x_global = 0.0;
    pos_y_global = 0.0;
    theta_actual = 0.0;
    error_acumulado_L = 0; error_anterior_L = 0;
    error_acumulado_R = 0; error_anterior_R = 0;
    target_L = 0; target_R = 0;
    portEXIT_CRITICAL(&paramMux);

    portENTER_CRITICAL(&timerMux);
    contador_L = 0; contador_R = 0;
    contador_L_ant = 0; contador_R_ant = 0;
    portEXIT_CRITICAL(&timerMux);
    
    sl_prev = 0; sr_prev = 0;

    digitalWrite(LED_PIN, LOW); delay(50); digitalWrite(LED_PIN, HIGH);
  }
}

void subscription_callback(const void *msgin) {
  const geometry_msgs__msg__Twist *msg = (const geometry_msgs__msg__Twist *)msgin;
  
  float linear_x = msg->linear.x;
  float angular_z = msg->angular.z;

  if (obstaculo_delante && linear_x > 0) {
    linear_x = 0; 
  }

  double vel_izq_ms = linear_x - (angular_z * ANCHO_ROBOT / 2.0);
  double vel_der_ms = linear_x + (angular_z * ANCHO_ROBOT / 2.0);

  portENTER_CRITICAL(&paramMux);
  target_L = vel_izq_ms / RADIO_RUEDA; 
  target_R = vel_der_ms / RADIO_RUEDA; 
  portEXIT_CRITICAL(&paramMux);
}

void subs_settings_callback(const void *msgin)
{
  const std_msgs__msg__Float32MultiArray *msg = (const std_msgs__msg__Float32MultiArray *)msgin;
  
  // Verificamos que el PC nos ha mandado al menos 3 valores para no leer memoria basura
  if (msg->data.size >= 3) {
    portENTER_CRITICAL(&paramMux);
    sensores[0].voltaje_mV_minimo = msg->data.data[0];
    sensores[1].voltaje_mV_minimo = msg->data.data[1];
    sensores[2].voltaje_mV_minimo = msg->data.data[2];
    portEXIT_CRITICAL(&paramMux);
    
    Serial.println("Umbrales de seguridad actualizados por ROS2");
  }
}

// ==========================================
//   SETUP
// ==========================================

void setup() {
  Serial.begin(115200);
  delay(1000);
  Serial.println("\n\n--- ARRANCANDO EL CEREBRO DEL ROBOT ---");

  Serial.println("1. Configurando motores...");
  pinMode(IN1_L, OUTPUT); pinMode(IN2_L, OUTPUT);
  pinMode(IN1_R, OUTPUT); pinMode(IN2_R, OUTPUT);
  pararMotores();

  ledcAttach(IN1_L, frecuencia, 10); ledcAttach(IN2_L, frecuencia, 10);
  ledcAttach(IN1_R, frecuencia, 10); ledcAttach(IN2_R, frecuencia, 10);

  Serial.println("2. Configurando encoders...");
  pinMode(PIN_A_L, INPUT_PULLUP); pinMode(PIN_B_L, INPUT_PULLUP);
  pinMode(PIN_A_R, INPUT_PULLUP); pinMode(PIN_B_R, INPUT_PULLUP);
  attachInterrupt(digitalPinToInterrupt(PIN_A_L), isr_L_A, CHANGE);
  attachInterrupt(digitalPinToInterrupt(PIN_B_L), isr_L_B, CHANGE);
  attachInterrupt(digitalPinToInterrupt(PIN_A_R), isr_R_A, CHANGE);
  attachInterrupt(digitalPinToInterrupt(PIN_B_R), isr_R_B, CHANGE);

  pinMode(LED_PIN, OUTPUT); digitalWrite(LED_PIN, HIGH);

  Serial.println("3. Inicializando sensores US-016...");
  // --- INIT SENSORES Y TAREA FREERTOS ---
  analogSetAttenuation(ADC_11db); 
  for (int s = 0; s < 3; s++) {
    inicializarSensor(sensores[s]);
  }
  Serial.println("4. Creando Tarea FreeRTOS...");
  xTaskCreate(tareaLecturaUS016, "Lectura_US016", 2048, NULL, 1, NULL);

  // --- WIFI Y MICRO-ROS ---
  Serial.println("5. Conectando al WiFi (Esto puede tardar)...");
  set_microros_wifi_transports("NOMBRE_WIFI", "CONTRASEÑA_WIFI", "IP_MV", 8888);

  while (WiFi.status() != WL_CONNECTED)
  {
    delay(500); Serial.print(".");
  }
  Serial.println("\n--- RED ---");
  Serial.println("WiFi Conectado correctamente");
  Serial.print("IP asignada al ESP32: ");
  Serial.println(WiFi.localIP());
  Serial.println("----------------");
  Serial.println("Esperando 2 segundos para estabilizar la red...");
  delay(2000);

  sistema_seguro = true;

  if (rmw_uros_ping_agent(1000, 3) != RMW_RET_OK)
  {
    Serial.println("Error Agente ROS"); error_loop();
  }

  allocator = rcl_get_default_allocator();
  RCCHECK(rclc_support_init(&support, 0, NULL, &allocator));
  RCCHECK(rclc_node_init_default(&node, "robot_esp32_node", "", &support));

  RCCHECK(rclc_publisher_init_best_effort(
    &publisher, &node,
    ROSIDL_GET_MSG_TYPE_SUPPORT(std_msgs, msg, Int32MultiArray), "/wheel_ticks"));

  // Inicialización del publicador Float32MultiArray
  RCCHECK(rclc_publisher_init_best_effort(
    &publisher_laser, &node,
    ROSIDL_GET_MSG_TYPE_SUPPORT(std_msgs, msg, Float32MultiArray), "/laser_scan"));

  RCCHECK(rclc_publisher_init_default(&pub_pos_estimada, &node, 
    ROSIDL_GET_MSG_TYPE_SUPPORT(geometry_msgs, msg, Point), "/posicion_estimada"));

  encoder_msg.data.capacity = 2;
  encoder_msg.data.size = 2;
  encoder_msg.data.data = (int32_t *)malloc(encoder_msg.data.capacity * sizeof(int32_t));

  // Asignar memoria para los 3 sensores
  laser_msg.data.capacity = 3;
  laser_msg.data.size = 3;
  laser_msg.data.data = (float *)malloc(laser_msg.data.capacity * sizeof(float));

  msg_sub_settings.data.capacity = 3;
  msg_sub_settings.data.size = 0; // Se inicializa a 0, micro-ROS lo actualiza al recibir
  msg_sub_settings.data.data = (float *)malloc(msg_sub_settings.data.capacity * sizeof(float));

  RCCHECK(rclc_subscription_init_best_effort(
    &subscriber, &node,
    ROSIDL_GET_MSG_TYPE_SUPPORT(geometry_msgs, msg, Twist), "cmd_vel"));

  RCCHECK(rclc_subscription_init_default(
    &subscriber_reset, &node,
    ROSIDL_GET_MSG_TYPE_SUPPORT(std_msgs, msg, Int32), "/reset_odometry"));

  RCCHECK(rclc_subscription_init_default(
    &subscriber_settings, &node,
    ROSIDL_GET_MSG_TYPE_SUPPORT(std_msgs, msg, Float32MultiArray), "/settings/robot"));

  RCCHECK(rclc_executor_init(&executor, &support.context, 3, &allocator));
  RCCHECK(rclc_executor_add_subscription(&executor, &subscriber, &msg_sub, &subscription_callback, ON_NEW_DATA));
  RCCHECK(rclc_executor_add_subscription(&executor, &subscriber_reset, &msg_reset, &reset_callback, ON_NEW_DATA));
  RCCHECK(rclc_executor_add_subscription(&executor, &subscriber_settings, &msg_sub_settings, &subs_settings_callback, ON_NEW_DATA));

  timer = timerBegin(1000000);
  timerAttachInterrupt(timer, &onTimerPID);
  timerAlarm(timer, 10000, true, 0); 

  Serial.println("--- SISTEMA OK (PID + 3 Sensores Crudos) ---");
}

// ==========================================
//   LOOP PRINCIPAL
// ==========================================

unsigned long last_pub_odom = 0;

void loop()
{
  if (WiFi.status() != WL_CONNECTED) {
    sistema_seguro = false;
    WiFi.disconnect(); WiFi.reconnect();
    delay(500); return;
  } else {
    if (!sistema_seguro) sistema_seguro = true;
  }

  RCSOFTCHECK(rclc_executor_spin_some(&executor, RCL_MS_TO_NS(1)));

  if (millis() - last_pub_odom > 50) { 
    last_pub_odom = millis();
    
    // --- LÓGICA OBSTÁCULOS POR MILIVOLTIOS ---
    
    if (sensores[0].voltaje_mV < sensores[0].voltaje_mV_minimo || 
        sensores[1].voltaje_mV < sensores[1].voltaje_mV_minimo || 
        sensores[2].voltaje_mV < sensores[2].voltaje_mV_minimo) {
       obstaculo_delante = true; 
       digitalWrite(LED_PIN, LOW); 
    } else {
       obstaculo_delante = false;
       digitalWrite(LED_PIN, HIGH);
    }

    // --- PUBLICAR POSICIÓN ---
    calcular_posicion();
    pos_msg.x = pos_x_global;
    pos_msg.y = pos_y_global;
    pos_msg.z = theta_actual;
    RCSOFTCHECK(rcl_publish(&pub_pos_estimada, &pos_msg, NULL));

    // --- PUBLICAR SENSORES (3 valores en mV) ---
    laser_msg.data.data[0] = sensores[0].voltaje_mV;
    laser_msg.data.data[1] = sensores[1].voltaje_mV;
    laser_msg.data.data[2] = sensores[2].voltaje_mV;
    RCSOFTCHECK(rcl_publish(&publisher_laser, &laser_msg, NULL));
  }
}

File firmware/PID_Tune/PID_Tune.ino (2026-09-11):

#include <Arduino.h>

// --- PINES ---
const int IN1 = 32;
const int IN2 = 33;
const int PIN_A = 25;
const int PIN_B = 26;

// --- CONFIGURACIÓN PWM ---
const int frecuencia = 1000;
const int resol = 10;      // 0-1023
const double MAX_PWM = 1023.0;

// --- TIEMPO DE MUESTREO ---
const float DELTA_T_S = 0.01; // 10ms

// --- VARIABLES PID ---
double Kp = 3.2;  
double Ki = 0.0; 
double Kd = 0.0; 

// Variables de estado
double referencia_posicion = 0.0;
double actuacion = 0.0;
double error_anterior = 0.0;
double suma_error = 0.0;

// --- VARIABLES ENCODER Y TIMER ---
volatile long contador = 0;
long contador_anterior = 0;

hw_timer_t *timer = NULL;
portMUX_TYPE timerMux = portMUX_INITIALIZER_UNLOCKED;

// --- INTERRUPCIONES ENCODER ---
void IRAM_ATTR manejador_interrupcion_A() {
  int a = digitalRead(PIN_A);
  int b = digitalRead(PIN_B);
  if (a == b) contador--; else contador++;
}

void IRAM_ATTR manejador_interrupcion_B() {
  int a = digitalRead(PIN_A);
  int b = digitalRead(PIN_B);
  if (a != b) contador--; else contador++;
}

// --- ACTUACIÓN MOTOR ---
void Ir_CW(int pwm_valor) {
  ledcWrite(IN1, pwm_valor);
  ledcWrite(IN2, 0);
}

void Ir_NCW(int pwm_valor) {
  ledcWrite(IN1, 0);
  ledcWrite(IN2, pwm_valor);
}

void Parar_Motor() {
  ledcWrite(IN1, 0);
  ledcWrite(IN2, 0);
}

void P3_actua_Segura(double actuacion_valor) {
  if (actuacion_valor > MAX_PWM) actuacion_valor = MAX_PWM;
  if (actuacion_valor < -MAX_PWM) actuacion_valor = -MAX_PWM;

  if (actuacion_valor > 0) Ir_CW((int)actuacion_valor);
  else if (actuacion_valor < 0) Ir_NCW((int)(-actuacion_valor));
  else Parar_Motor();
}

// --- ALGORITMO PID ---
void P3_PID_Segura(double referencia, double valor_actual) {
  double error = referencia - valor_actual;

  if (Ki > 0) {
    suma_error += error;
    
    // Anti-windup
    double max_suma = MAX_PWM / Ki;
    
    if (suma_error > max_suma) suma_error = max_suma;
    if (suma_error < -max_suma) suma_error = -max_suma;
  } else {
    suma_error = 0;
  }

  actuacion = (Kp * error) + (Ki * suma_error) + (Kd * (error - error_anterior));

  error_anterior = error;
}

// --- INTERRUPCIÓN TIMER ---
void IRAM_ATTR ISR_Control_PID() {
  long pos_actual;
  portENTER_CRITICAL_ISR(&timerMux);
  pos_actual = contador;
  portEXIT_CRITICAL_ISR(&timerMux);

  P3_PID_Segura(referencia_posicion, (double)pos_actual);
  P3_actua_Segura(actuacion);
}

void setup() {
  Serial.begin(115200);

  // PWM
  ledcAttach(IN1, frecuencia, resol);
  ledcAttach(IN2, frecuencia, resol);

  // Encoder
  pinMode(PIN_A, INPUT_PULLUP);
  pinMode(PIN_B, INPUT_PULLUP);
  attachInterrupt(digitalPinToInterrupt(PIN_A), manejador_interrupcion_A, CHANGE);
  attachInterrupt(digitalPinToInterrupt(PIN_B), manejador_interrupcion_B, CHANGE);

  timer = timerBegin(1000000); 
  timerAttachInterrupt(timer, &ISR_Control_PID);
  timerAlarm(timer, 10000, true, 0); // 10ms

  Serial.println("MODO DIRECTO: Kp, Ki, Kd.");
  Serial.println("Ejemplos: 'P 1.5', 'I 0.05', 'D 2.0' o '1000' (Ref)");
  Serial.println("Referencia,Posicion"); 
}

void loop() {
  // --- LECTURA COMANDOS ---
  if (Serial.available() > 0) {
    String entrada = Serial.readStringUntil('\n');
    entrada.trim(); 

    if (entrada.length() > 0) {
      char comando = toupper(entrada.charAt(0)); 

      if (comando == 'P' || comando == 'I' || comando == 'D') {
        double valor = entrada.substring(1).toDouble();

        if (comando == 'P') Kp = valor;
        if (comando == 'I') Ki = valor;
        if (comando == 'D') Kd = valor;

        Serial.print(">> SET PID | Kp:"); Serial.print(Kp);
        Serial.print(" Ki:"); Serial.print(Ki);
        Serial.print(" Kd:"); Serial.println(Kd);

      } else {
        referencia_posicion = entrada.toDouble();
      
        // Reset para estabilidad en el nuevo salto
        portENTER_CRITICAL(&timerMux);
        suma_error = 0.0;
        error_anterior = 0.0;
        portEXIT_CRITICAL(&timerMux);
      }
    }
  }

  // --- TELEMETRÍA (Excel) ---
  static unsigned long last_print = 0;
  if (millis() - last_print >= 50) {
    last_print = millis();
    
    long pos_print;
    portENTER_CRITICAL(&timerMux);
    pos_print = contador;
    portEXIT_CRITICAL(&timerMux);

    // CSV
    Serial.print(referencia_posicion);
    Serial.print(",");
    Serial.println(pos_print);
  }
}

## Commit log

2026-09-11 Revise chassis and drive specifications in README
    Updated chassis material and drive system details in README.
2026-09-11 new changes
    [EnsamblajeRobot.SLDASM, MainBase.SLDPRT, MainBase.STL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]
2026-09-11 more changes in README
    [EnsamblajeRobot.SLDASM]
